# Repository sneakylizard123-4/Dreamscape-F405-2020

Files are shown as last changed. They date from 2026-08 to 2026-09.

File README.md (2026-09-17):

# Dreamscape F405

a 20x20mm flight controller for 3" fpv drone

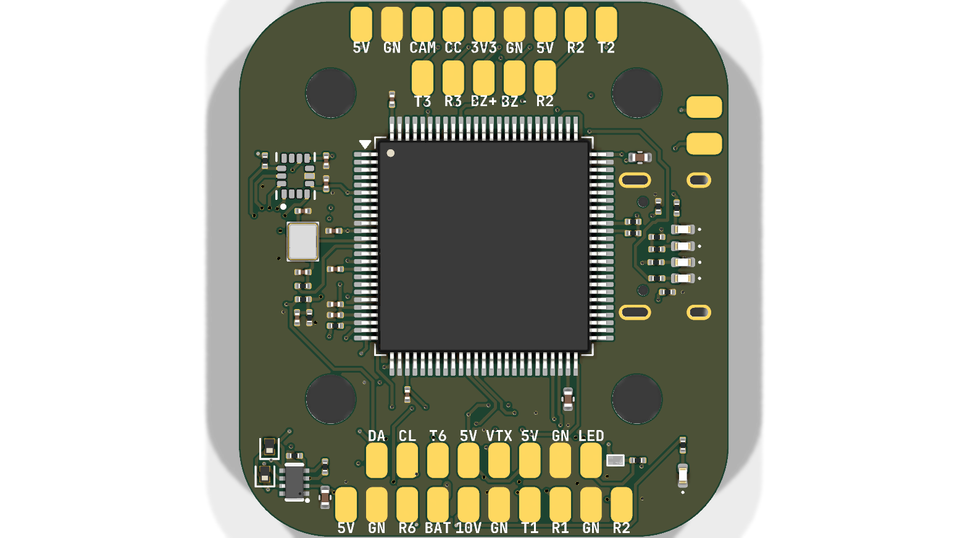
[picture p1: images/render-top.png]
PCB render


## Why I made this

would be a nice portfolio project
if it works i save lots of money too

## Pictures

| Page | Sheet |
|---|---|
| 1 | [Root / block diagram](images/schematic/Dreamscape-F405-2020.png) |
| 2 | [Power](images/schematic/Dreamscape-F405-2020-Power.png) |
| 3 | [Sensors](images/schematic/Dreamscape-F405-2020-Sensors.png) |
| 4 | [Blackbox](images/schematic/Dreamscape-F405-2020-Blackbox.png) |
| 5 | [OSD](images/schematic/Dreamscape-F405-2020-OSD.png) |
| 6 | [STM32](images/schematic/Dreamscape-F405-2020-STM32.png) |
| 7 | [Pads / connectors](images/schematic/Dreamscape-F405-2020-Pads.png) |
| 8 | [USB](images/schematic/Dreamscape-F405-2020-USB.png) |

## Features

- **MCU**: STM32F405VGT6
- **IMU**: ICM-42688-P
- **Barometer**: BMP280
- **OSD**: AT7456E (MAX7456-compatible)
- **Blackbox**: full-size microSD slot
- **Receiver**: dedicated JST-SH 4-pin ExpressLRS connector
- **UARTs**: 4 exposed plus I2C pads
- **Power**:
  - Battery input up to 6S
  - 5 V rail: onboard buck regulator
  - 3.3 V rail: TLV75733 LDO
  - 10 V rail: separate buck to feed camera/VTX
  - Onboard battery voltage ADC divider and ESC current sensor input
- **Extras**: beeper driver, neopixel LED strip driver, status LEDs

## Power tree

```mermaid
graph LR
    BAT[Battery +BATT] --> BUCK10[LMR51430 buck]
    BAT --> BUCK5[LMR51430 buck]
    BUCK10 -->|10 V, switched by 10V_EN| R10[CAM / VTX]
    BUCK5 -->|+5V_BUCK| MUX[TPS2116 power mux]
    USB[USB +5V] --> MUX
    MUX -->|system +5V| PERIPH[OSD / ELRS / peripherals]
    PERIPH --> LDO[TLV75733 LDO]
    LDO -->|+3.3V| MCU[STM32F405 / sensors]
```

## Pinout

Solder pads along the edge:

| Pad | Function | Pad | Function |
|---|---|---|---|
| `BAT` | Battery positive | `G` | Ground |
| `3v3` | 3.3 V out | `5v` | 5 V out |
| `10v` | 10 V out (switchable) | `CUR` | ESC current sense in |
| `TEL` | ESC telemetry | `CC` | Camera control |
| `CAM` | Video in from camera | `VTX` | Video out to VTX |
| `M1`-`M4` | Motor PWM outputs | `LED` | Addressable LED strip |
| `BZ+`/`BZ-` | Beeper | `SDA`/`SCL` | I2C |
| `T1`/`R1` | UART1 TX/RX | `T2`/`R2` | UART2 TX/RX |
| `T3`/`R3` | UART3 TX/RX | `T6`/`R6` | UART6 TX/RX |

Connectors:

| Connector | Pins | Use |
|---|---|---|
| J41 - JST-SH 8-pin vertical | BAT, GND, CUR, TEL, M1-M4 | battery + ESC harness |
| J42 - JST-SH 4-pin horizontal | 5V, GND, TX, RX | ExpressLRS receiver |

## Assembly

you probably should get pcba

solder front side first.
hand solder back side

## Flashing

drag the `.bin` onto the mounted DFU drive using the Betaflight Configurator firmware flasher.

Notes:
- If DFU is not accessible, flash via SWD with an ST-Link and `STM32_Programmer_CLI` or OpenOCD instead.

## Known Issues

- Board hasn't been manufactured yet.

## Credits

- OpenDrone
- Betaflight project - firmware this board will run
- STMicroelectronics / TDK / Bosch / Analog Devices datasheets for part reference designs

---

## BOM

| Refs | Part | Package / Footprint | Notes |
|---|---|---|---|
| U1 | STM32F405VGT6 | LQFP-100 14x14 mm | main MCU, 168 MHz Cortex-M4 |
| U6 | ICM-42688-P | LGA-14 | gyro + accel |
| U7 | BMP280 | LGA-8 | barometer |
| U8 | AT7456E | TQFP | MAX7456-compatible OSD |
| Y1 | 27 MHz crystal | 2016 4-pad | OSD clock |
| Card1 | TF-021B-H265 | microSD push-pull slot | blackbox logging |
| U3, U4 | LMR51430 | SOT-23-6 | 3 A buck regulators (10 V and 5 V) |
| U5 | TPS2116DRLR | SOT-583-8 | USB/buck power mux |
| U2 | TLV75733PDBV | SOT-23-5 | 3.3 V LDO |
| Q5, Q6 | AP1606 | DFN-3 | beeper and LED strip drivers |
| D3, D6 | RB161QS-40 | SOD-882 | Schottky diodes (power path) |
| L2, L3 | XRTC303020D4R7 | 3x3 mm | 4.7 uH power inductors |
| D2 | Blue LED | 0402 | status |
| D4, D5, D7 | Green LED | 0402 | power indicators |
| J41 | JST-SH 8-pin | SM08B-SHLS-TF | battery/ESC harness |
| J42 | JST-SH 4-pin | SM04B-SRSS-TB | ELRS receiver |
| R31, R29, R27, R23, R50 | 100 kOhm x5 | 0201 | |
| R2, R39, R49, R50 | 10 kOhm x4 | 0201 | VBAT divider / pull-ups |
| R28 | 39 kOhm | 0201 | buck feedback divider |
| R34, R33 | 7.5 kOhm x2 | 0201 | buck feedback dividers |
| R32 | 13.7 kOhm | 0201 | buck feedback |
| R30 | 6.49 kOhm | 0201 | buck feedback |
| R53, R52 | 75 Ohm x2 | 0201 | |
| R36 | 510 Ohm | 0201 | |
| R51 | 2.4 kOhm | 0201 | |
| R9 | 1 kOhm | 0201 | current sensor filter |
| C24, C25 | 4.7 uF 50 V x2 | 0805 | battery input |
| C29, C28, C34 | 22 uF x3 | 0603/0402 | buck outputs |
| C30 | 4.7 uF | 0402 | |
| C1, C22 | 2.2 uF x2 | 0402 | |
| C4, C36-C39, C43, C32, C26, C27 | 100 nF x10 | 0201 | decoupling |

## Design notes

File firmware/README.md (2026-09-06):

# Firmware

This board runs [Betaflight](https://betaflight.github.io/) (GPL-3.0), pinned here as a git submodule in `betaflight/`.

## Current version

- Submodule commit: `142ed9a` (master, 2026-08-28)

## Building

See `betaflight/` for the standard Betaflight build setup (arm-none-eabi-gcc + Makefile). The custom part for this board is a unified target config mapping:

- SPI1 = ICM-42688-P gyro/accel + BMP280 barometer
- SPI2 = AT7456E OSD
- SPI3 = microSD blackbox
- UART1/2/3/6 = pads T1-T6 / R1-R6
- motor timers, beeper, LED strip, VBAT/current ADC

## Updating the submodule

```sh
git submodule update --remote firmware/betaflight   # pull latest
```

Clone with submodules:

```sh
git clone --recursive <this repo>
```

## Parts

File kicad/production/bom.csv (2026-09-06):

Designator | Footprint | Quantity | Value | LCSC Part #
C1, C2 | 0805 | 2 | 4.7uF 50v | C98192
C10 | 0402 | 1 | 4.7uF | C23733
C11, C4 | 0402 | 2 | 22uF | C415703
C12, C13, C14, C15, C16, C17, C19, C21, C23, C25, C26, C27, C3, C5, C6, C9 | 0201 | 16 | 100n | C76939
C18, C20 | 0402 | 2 | 2.2uF
C22, C24 | 0201 | 2 | 20pF | C76923
C7, C8 | 0603 | 2 | 22uF | C2762594
CARD1 | TF-SMD_TF-021B-H265 | 1 | TF-021B-H265 | C498185
D1, D2, D3, D6 | 0402 | 4 | LED_1_Green | C965793
D4, D5 | D_SOD-882 | 2 | RB161QS-40_C28646385 | C28646385
D7 | 0402 | 1 | LED_1_Blue | C22355736
J35 | JST_SHL_SM08B-SHLS-TF_1x08-1MP_P1.00mm_Horizontal | 1 | Conn_01x08_MountingPin
J36 | JST_SH_SM04B-SRSS-TB_1x04-1MP_P1.00mm_Horizontal | 1 | Conn_01x04_MountingPin
J37 | USB_C_Receptacle_HRO_TYPE-C-31-M-12 | 1 | USB_C_Receptacle_USB2.0_16P
L1, L2 | IND-SMD_L3.0-W3.0_AFE303020S | 2 | XRTC303020D4R7MBCA | C39846837
Q1, Q2 | DFN-3L_L1.0-W0.6-P0.65-BR | 2 | AP1606 | C2849580
R1, R10, R24 | 0201 | 3 | 510R | C57784
R11, R12, R13, R16, R17, R19 | 0201 | 6 | 10k | C106225
R14, R15, R27, R28 | 0201 | 4 | 5.1k | C270344
R18, R2, R26, R4, R6 | 0201 | 5 | 100k | C270364
R20, R21 | 0201 | 2 | 1k | C270365
R22, R23 | 0201 | 2 | 75R | C274878
R25 | 0201 | 1 | 2.4k | C166281
R3 | 0201 | 1 | 6.49k | C2107920
R5 | 0201 | 1 | 13.7k | C320695
R7 | 0201 | 1 | 39k | C473053
R8, R9 | 0201 | 2 | 7.5k | C474437
U1, U5 | SOT-23-5 | 2 | TLV75733PDBV
U11, U12 | SW-SMD_4P-L3.0-W2.0-P0.85-LS3.5 | 2 | TS2306A 240GF MSM 9_C2976675 | C2976675
U2, U3 | SOT-23-6 | 2 | LMR51430
U4 | SOT-583-8_L2.1-W1.6-P0.50-LS1.6-BL | 1 | TPS2116DRLR | C3235557
U6 | PQFN50P300X250X97-14N | 1 | ICM-42688-P
U7 | Bosch_LGA-8_2x2.5mm_P0.65mm_ClockwisePinNumbering | 1 | BMP280
U8 | 21-0108G_U28E-5_MXM | 1 | AT7456E
U9 | LQFP-100_14x14mm_P0.5mm | 1 | STM32F405VGTx
X1 | CRYSTAL-SMD_4P-L2.5-W2.0-BL-A | 1 | X32258MOB4SI | C2682775
Y1 | Crystal_SMD_2016-4Pin_2.0x1.6mm | 1 | 27MHz

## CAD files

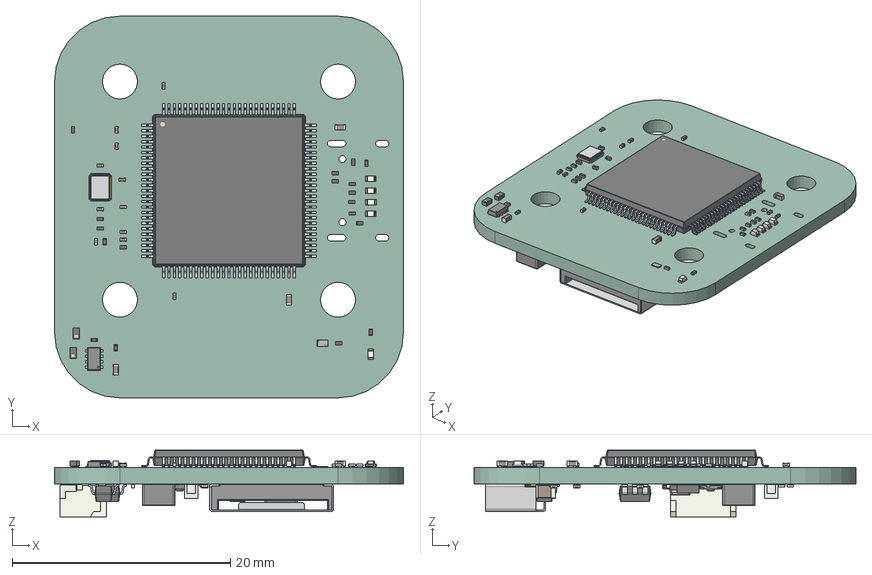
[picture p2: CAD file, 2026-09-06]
cad/Dreamscape-F405-2020.step
32.0 x 35.0 x 6.14 mm
LED_0402_1005Metric x 5
R_0201_0603Metric x 28
C_0201_0603Metric x 18
C_0402_1005Metric x 5
SOT-583-8_L2.1-W1.6-P0.50-LS1.6-BL
LQFP-100_14x14mm_P0.5mm
CRYSTAL-SMD_4P-L2.5-W2.0-BL-A
DFN-3L_L1.0-W0.6-H0.5-P0.65-BR x 2
D_SOD-882 x 2
IND-SMD_L3.0-W3.0_AFE303020S x 2
SW-SMD_4P-L3.0-W2.0-P0.85-LS3.5 x 2
TF-SMD_TF-021B-H265
C_0603_1608Metric x 2
SOT-23-6 x 2
Crystal_SMD_2016-4Pin_2.0x1.6mm
C_0805_2012Metric x 2
JST_SH_SM04B-SRSS-TB_1x04-1MP_P1.00mm_Horizontal
SOT-23-5 x 2
Bosch_LGA_8_2x25mm_P065mm_ClockwisePinNumbering
Dreamscape-F405-2020_PCB

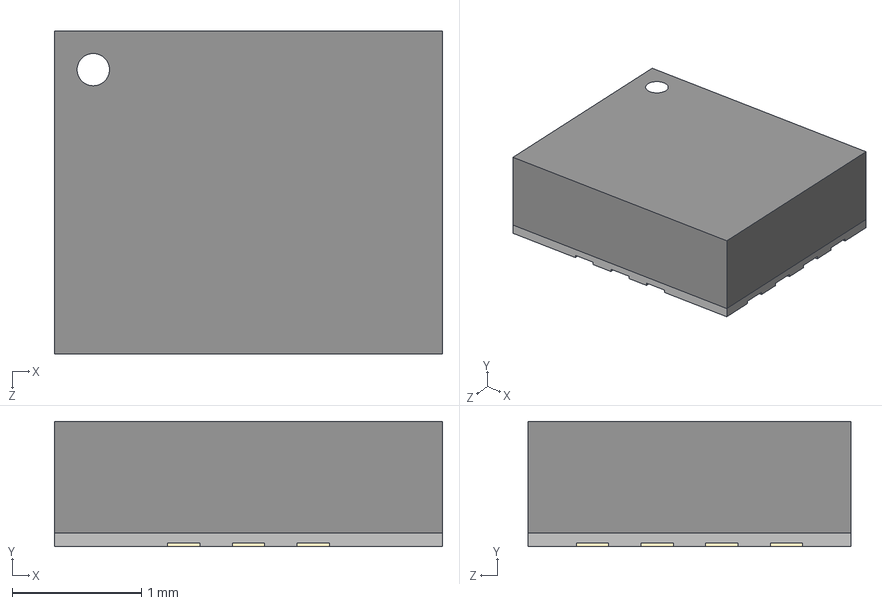
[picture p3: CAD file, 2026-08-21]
kicad/parts/ICM_42688_P/ICM-42688-P.step
3.00 x 0.97 x 2.50 mm

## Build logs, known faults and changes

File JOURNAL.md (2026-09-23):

---
title: Dreamscape F405 devlog
author: sneakylizard123-4
description: Building a custom STM32F405 flight controller from scratch
created_at: 2026-08-02
---

# August 2: Picking a brain (and the parts around it)

## What I did:

- started the project
- picked the brain: STM32F405, the same chip most modern flight controllers run
- settled on a 20x20 mounting pattern so it fits standard quad stacks
- planning a 3" fpv drone around it
- picked the rest of the part list:
    - ICM-42688-P IMU
    - BMP280 barometer
    - AT7456E OSD

## Why:

- last builds used off-the-shelf flight controllers, this one is mine end to end
- everything on one board, no stacking random modules

## Screenshots:

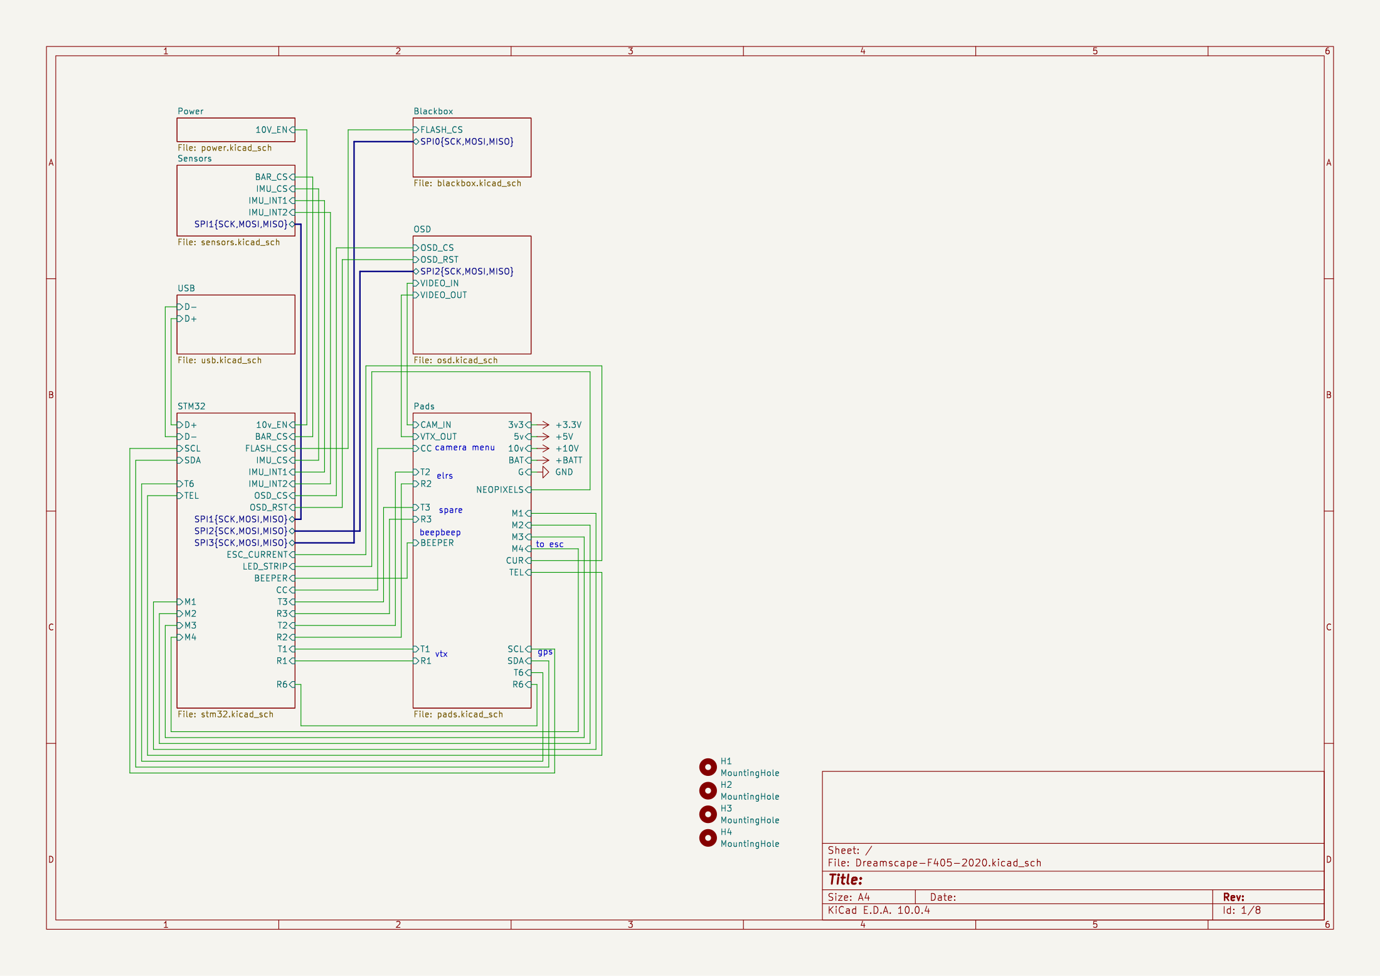
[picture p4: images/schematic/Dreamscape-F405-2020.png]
the plan


**Total time spent: 3 hours**

# August 5: Power sheet

## What I did:

- first sheet: power
- two LMR51430 bucks: a 5v rail always on, a 10v rail gated by an enable pin
- TLV75733 LDO drops 5v to 3.3v for the logic
- TPS2116 power mux picks between the 5v buck and USB 5v
- resistor divider onto an ADC pin to read battery voltage

## Why:

- camera and VTX want 10v but only when armed, so the gate keeps them off on the bench
- the mux means the board boots off USB with no battery plugged in
- battery divider sized so 6S stays under the MCU's 3.3v

## Screenshots:

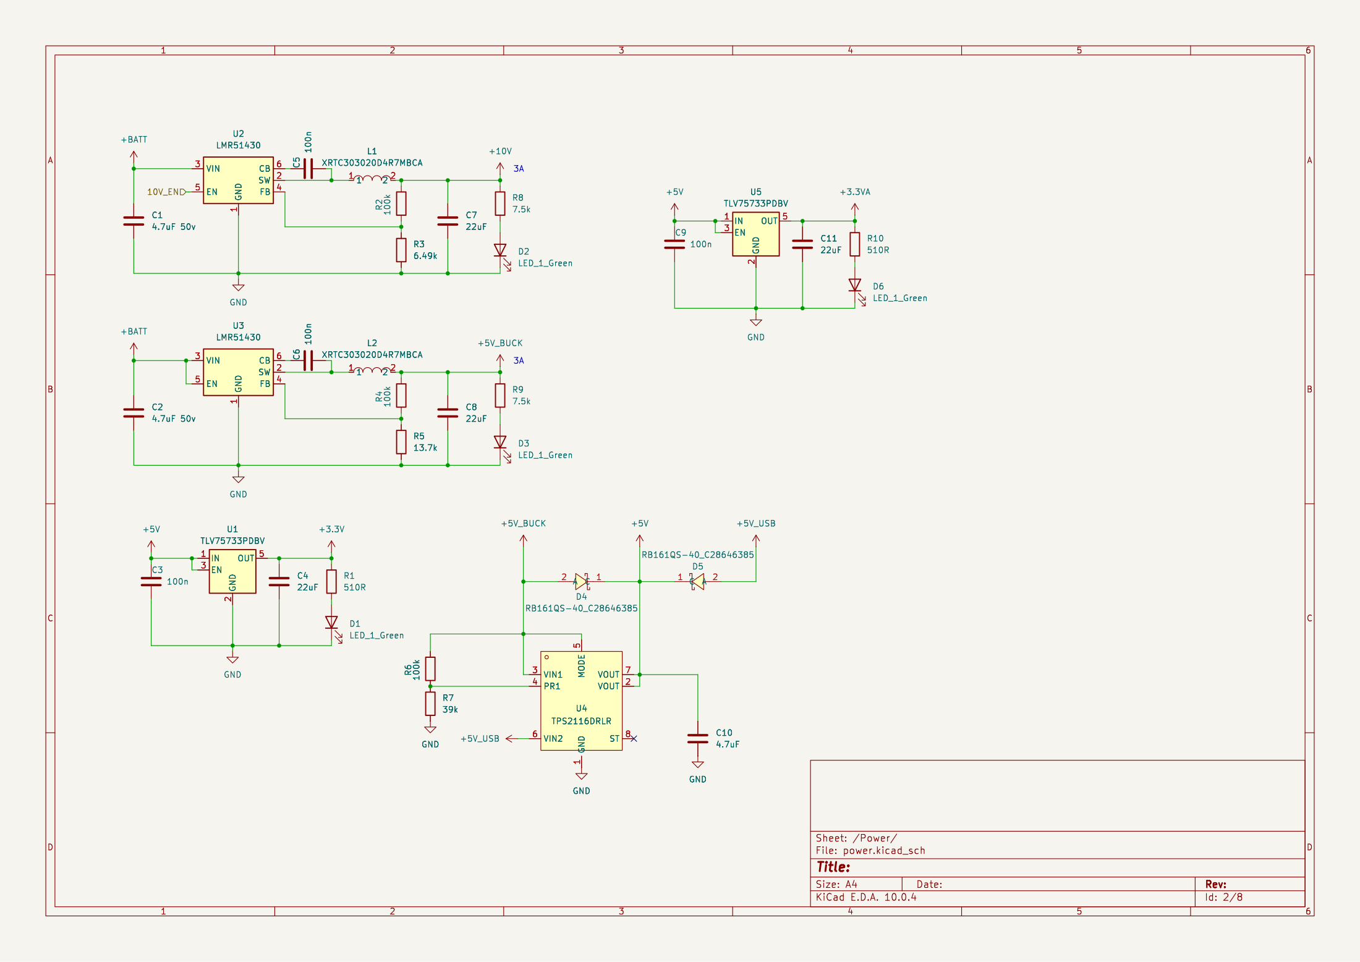
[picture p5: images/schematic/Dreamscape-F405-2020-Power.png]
power sheet


**Total time spent: 3 hours**

# August 8: Sensors sheet

## What I did:

- ICM-42688-P IMU
- BMP280 barometer
- both on the same SPI1 bus, separate chip selects
- copied reference circuits for the decoupling

## Why:

- the IMU is the core of the flight controller, went with the modern part instead of the old 6xx series
- baro gives pressure hold for free, costs one more chip
- sharing one SPI bus saves pins, chip select keeps them from talking over each other

## Screenshots:

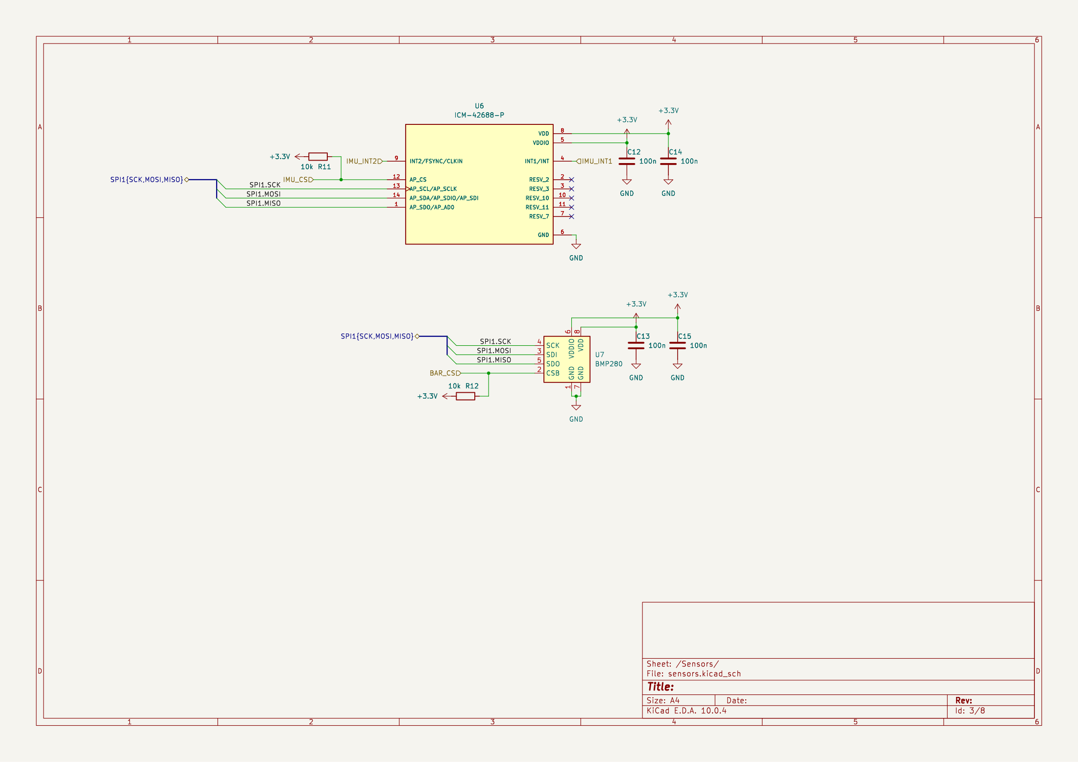
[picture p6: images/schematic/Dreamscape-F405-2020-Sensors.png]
sensors sheet


**Total time spent: 2 hours**

# August 11: Blackbox sheet

## What I did:

- microSD slot on its own SPI3 bus
- push-pull slot so a card clicks in
- card select pulled up, unused data lines left in SPI mode

## Why:

- blackbox logging writes constantly, didn't want it fighting the gyro for the bus
- a stuck card read could delay the IMU and wreck flight behavior

## Screenshots:

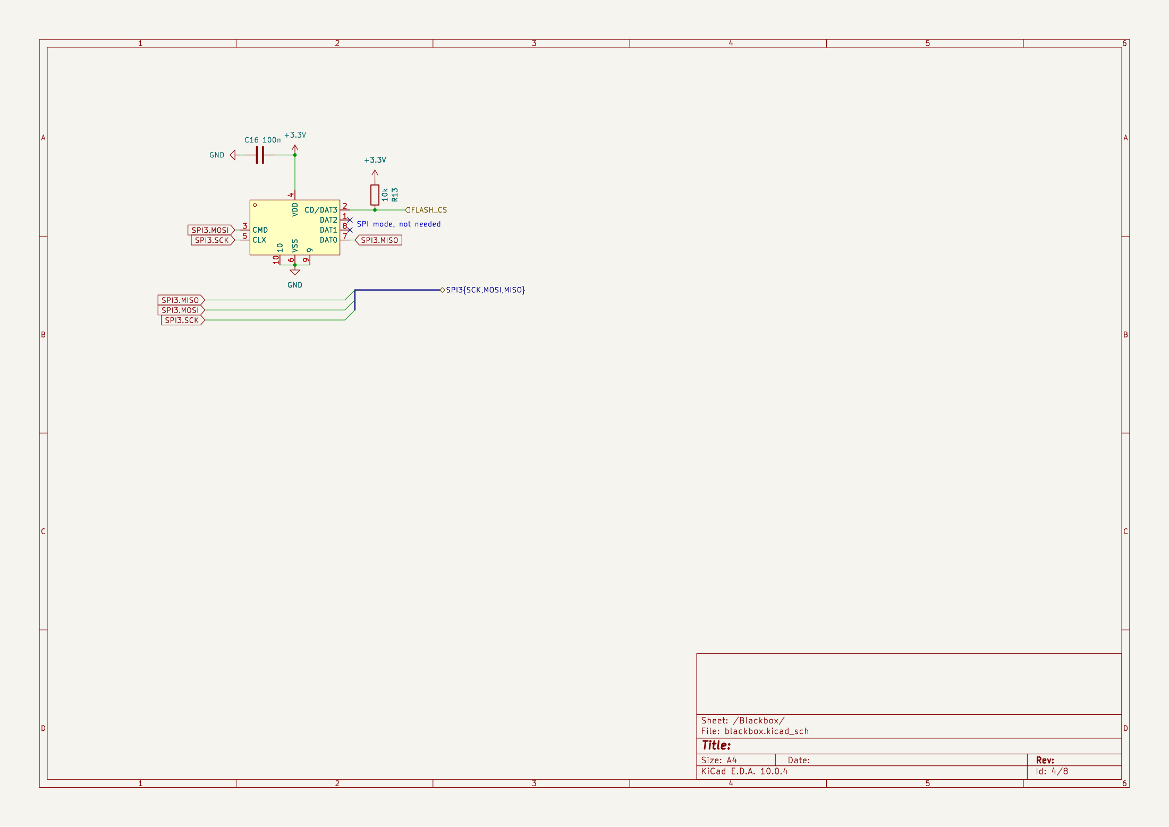
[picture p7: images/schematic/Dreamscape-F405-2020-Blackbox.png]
blackbox sheet


**Total time spent: 2 hours**

# August 14: OSD sheet

## What I did:

- AT7456E for the overlay
- 27MHz crystal it needs
- kept the signal path straight: Camera -> OSD -> VTX

## Why:

- AT7456E is everywhere in FPV, tons of reference material
- the video path is analog and easy to mess up, short and clean is the only sane option

## Screenshots:

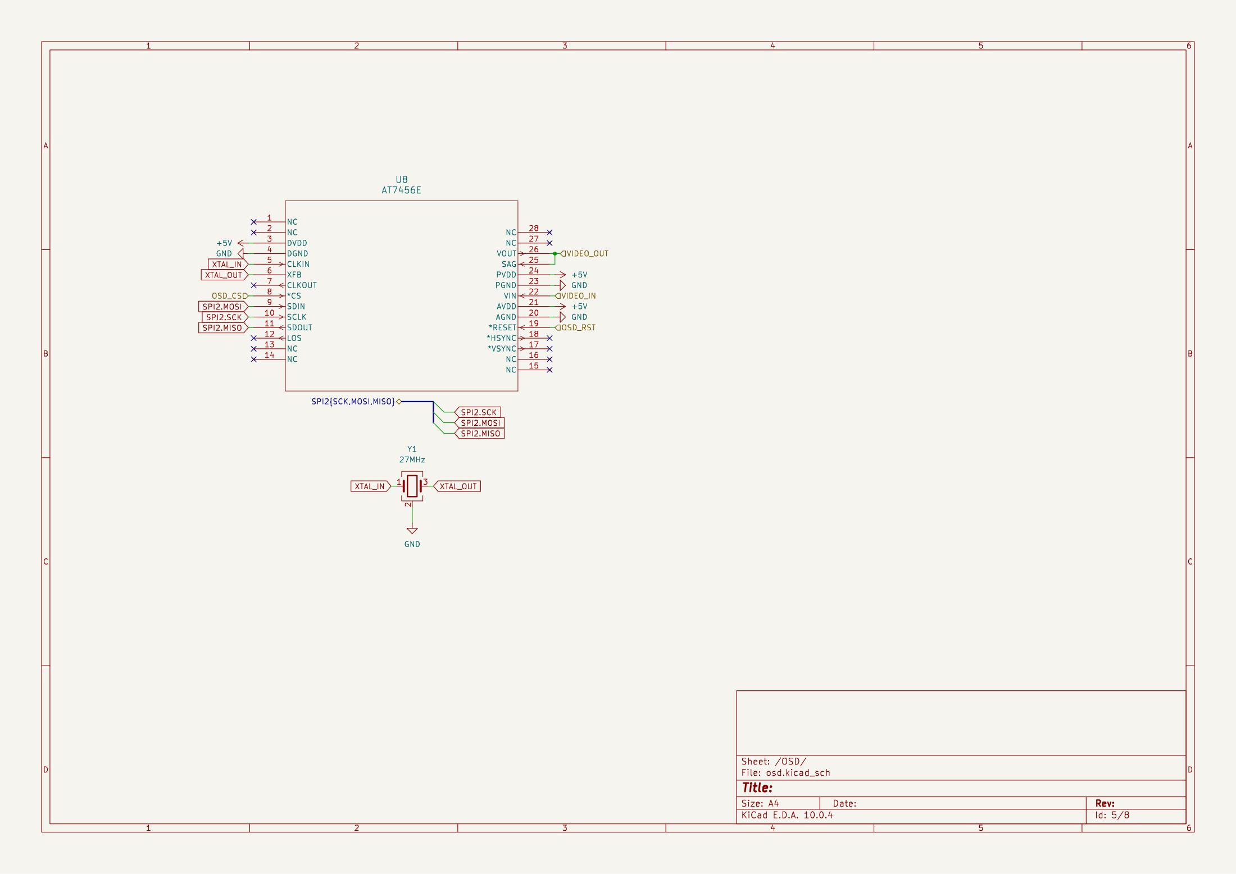
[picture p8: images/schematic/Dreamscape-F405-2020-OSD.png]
osd sheet


**Total time spent: 2 hours**

# August 18: STM32 sheet

## What I did:

- started the f405 sheet
- 8MHz crystal on PH0/PH1
- this chip has USB built in, no transceiver chip needed
- spent a long time on pin assignment, matching each pad to pins with the right alternate function

## Why:

- pin choice decides the whole board, worth doing carefully upfront instead of rerouting later
- USB means flashing over the type-C port, no extra chip

## Screenshots:

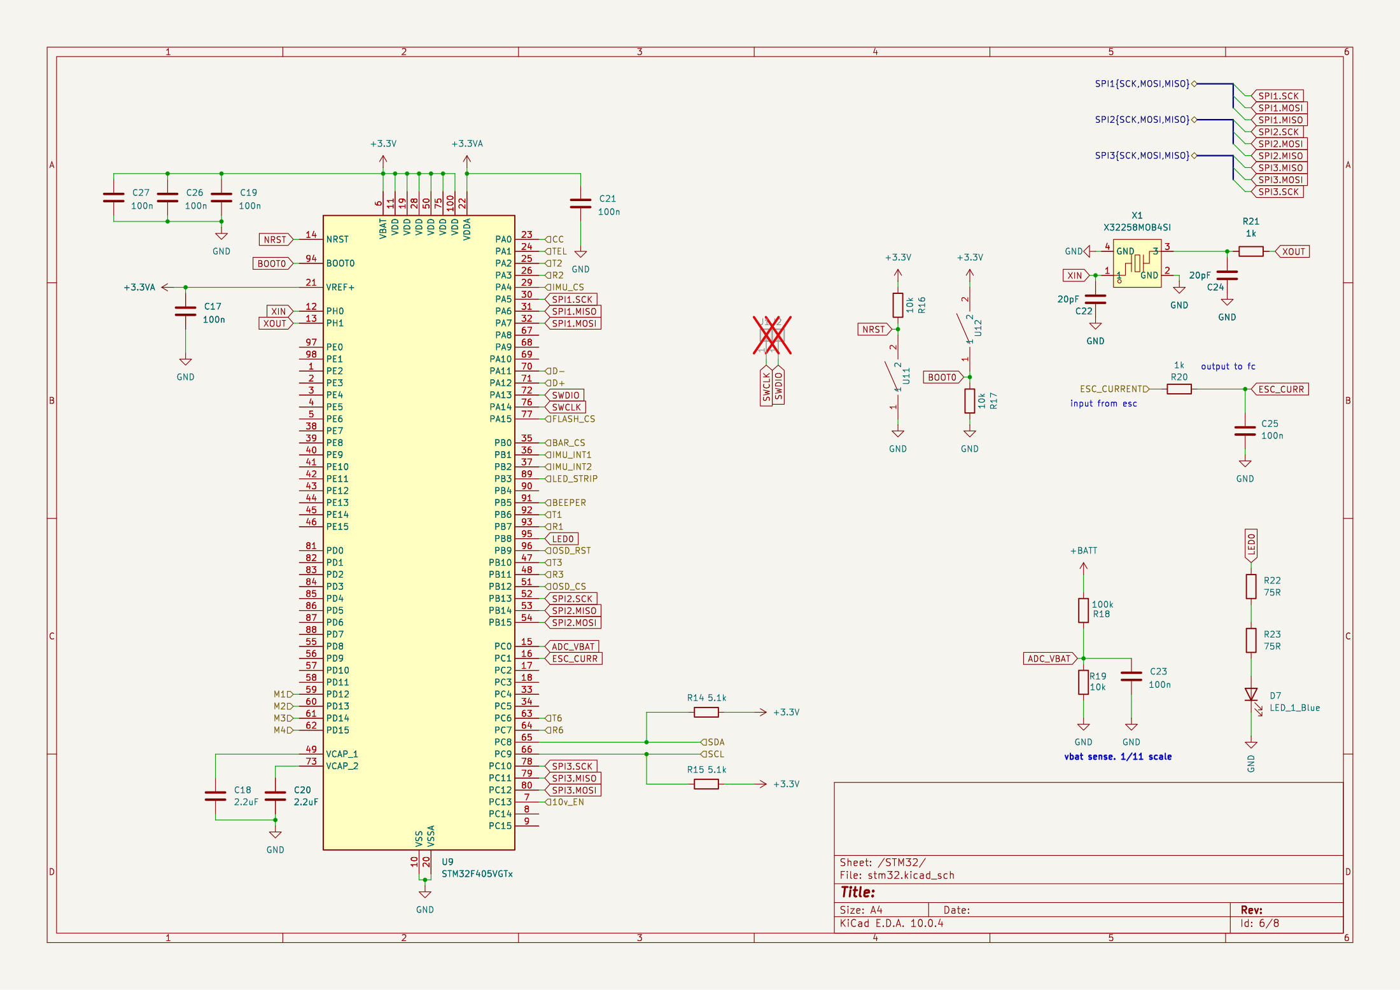
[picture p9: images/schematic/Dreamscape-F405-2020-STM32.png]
stm32 sheet


**Total time spent: 4 hours**

# August 20: Pads sheet

## What I did:

- pads sheet
- JST-SH connector for the ESCs and the battery/telemetry/current harness
- separate header for the ELRS receiver
- modeled on the F405 Mini pad layout

## Why:

- JST-SH is what flight controllers actually ship with, plugs match common motor and ext boards
- separate ELRS connector keeps the radio wiring clean

## Screenshots:

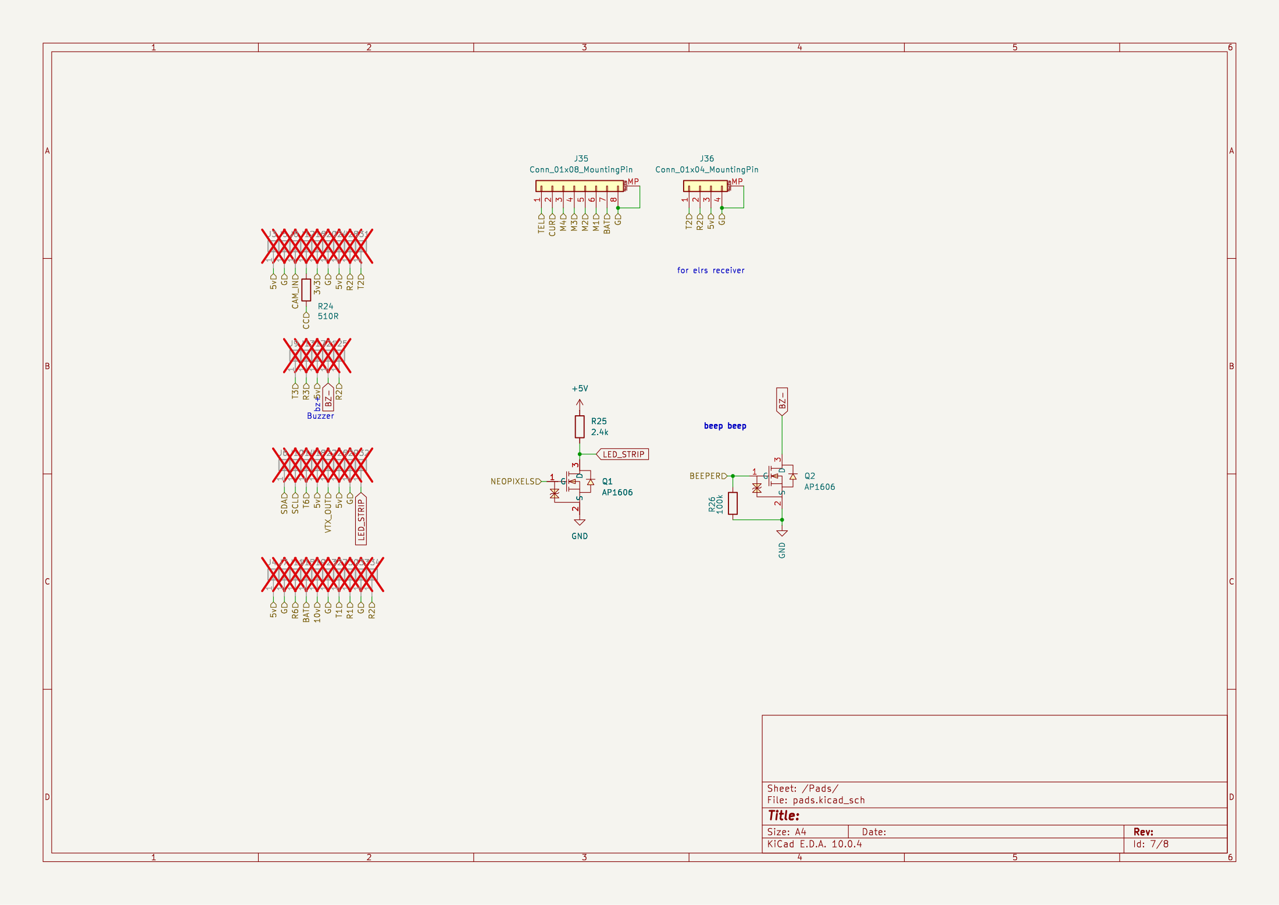
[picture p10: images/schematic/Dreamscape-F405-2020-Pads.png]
pads sheet


**Total time spent: 3 hours**

# August 22: USB-C sheet

## What I did:

- USB-C sheet
- VBUS goes into the power mux
- 5.1k CC pull-downs

## Why:

- standard USB-C connector is cheap and everywhere
- plugging in USB powers the board through the mux, no battery needed to flash

## Screenshots:

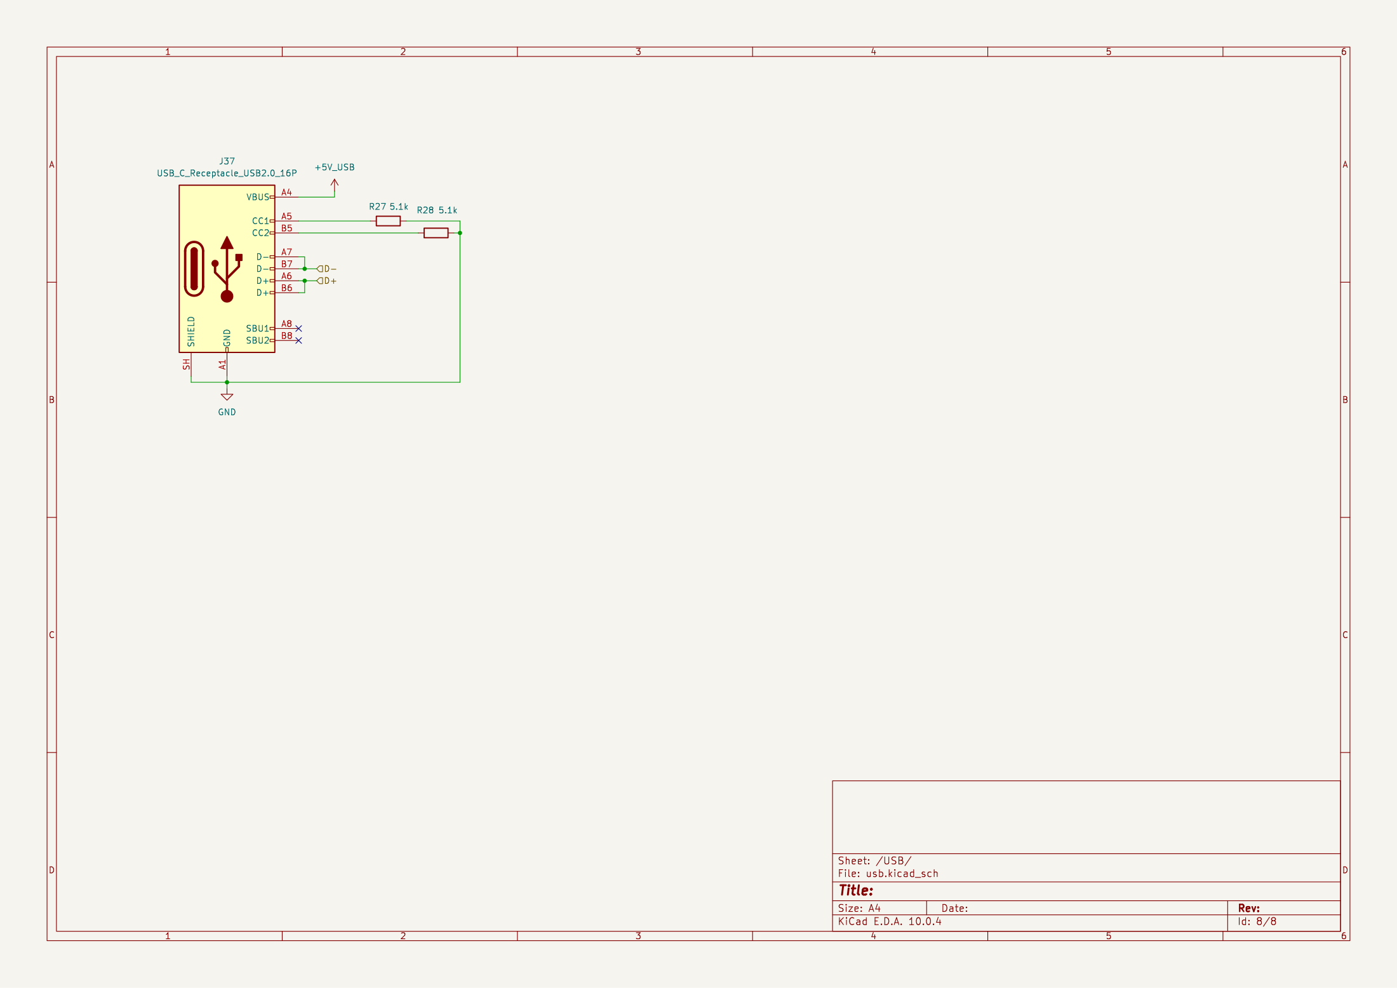
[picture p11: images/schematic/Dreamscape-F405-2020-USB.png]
usb sheet


**Total time spent: 1.5 hours**

# August 25: Placement and start of routing

## What I did:

- started the PCB
- F405 in the center
- power stage along one edge
- analog stuff kept away from the buck converters
- inner ground plane

## Why:

- traces near the power stage carry switching noise, keeping analog away saves headaches
- the ground plane gives clean return paths

## Screenshots:

board so far

**Total time spent: 4 hours**

# August 27: Routing done (+ DRC)

## What I did:

- finished routing both layers
- ran DRC: clearance issues near the crystal, some silk too close to pads
- retraced the current sense line, it ran past both bucks on its way to the ESC

## Why:

- power traces carry huge ripple, the current sense pickoff needed a cleaner route
- left the cosmetic DRC leftovers for the cleanup pass

## Screenshots:

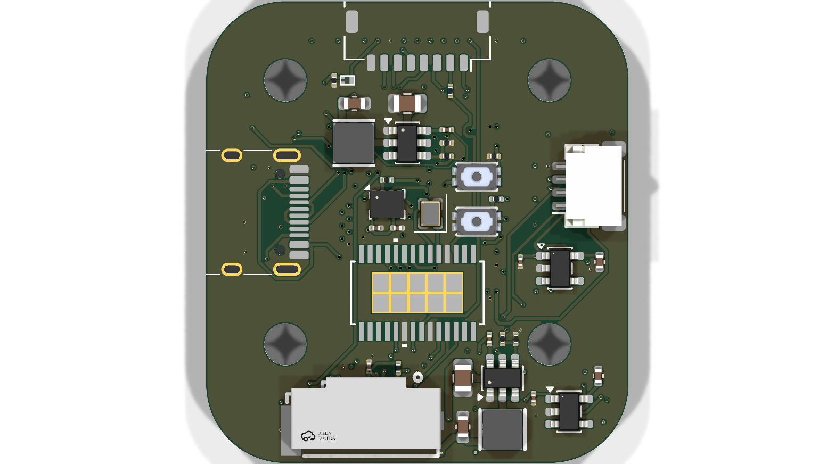
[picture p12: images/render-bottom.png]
finished routing


**Total time spent: 6 hours**

# August 28: Silkscreen labels on the pads

## What I did:

- labeled every pad in silkscreen
- 5v, gn, 3v3, 10v, bat, bz, led, cam, vtx, the UART pads
- shortened names so they fit on a 20x20 board

## Why:

- every real flight controller has this, makes wiring the stack at the bench not guesswork
- 0201 parts and pad labels in one place is cramped, spacing got fiddly, expect careful soldering

## Screenshots:

Fresh PCB render with the pad labels

**Total time spent: 1 hour**

# August 29: Design review by a second pair of eyes

## What I did:

- Forge wants the design sanity-checked by someone else, so I sent the board out for review
- the reviewer mapped every MCU pin against the STM32F405 datasheet
- went through SPI1/2/3, the UARTs, USB, the power tree, and the motor timers
- the reviewer found a real bug: the I2C pads landed on pins that can't do I2C on the F405

## Why:

- a reviewed design is cheaper to fix than a fabbed one
- I had assumed the pads were fine, fresh eyes caught what I'd stopped looking at

## Screenshots:

stm32 sheet under review

**Total time spent: 3 hours**

# August 30: Fixing the I2C wiring

## What I did:

- SDA pad was on PC8: no I2C alternate function there at all
- SCL was on PC9, which is actually the I2C3 SDA pin, so they were backwards too
- re-routed SDA to PC9 and SCL to PA8, the pins that really can do I2C3
- re-ran ERC and DRC after the change
- regenerated the schematic PNGs so the repo images match the fix

## Why:

- the chip is labeled I2C3 on those pins in the datasheet, the pad wiring had drifted from it
- catching it before fab saved a dead pair of pads in the final board

## Screenshots:

pads sheet after fix

**Total time spent: 2 hours**

# August 31: Firmware drop-in and STEP export

## What I did:

- added Betaflight as a git submodule under firmware/
- noted which target config to build from: SPI1 gyro and baro, SPI2 OSD, SPI3 SD, UART pads for the radio and GPS
- exported the board as STEP for the CAD requirement

## Why:

- the board is built to run stock Betaflight, keeping it as a submodule pins the upstream version we target
- the STEP export is required for submission and doubles as a sanity check of the 3D models

## Screenshots:

board render for the CAD pass

**Total time spent: 2 hours**

# September 1: Repo cleanup and submission prep

## What I did:

- rewrote the README to the Hack Club template
- reworked the journal into the what/why/screenshots format
- added a gitignore so the kicad autosave junk stays out of the repo
- noticed the JST-SH connector has no 3D model, so it shows up missing in the STEP export

## Why:

- submission needs the repo organized: BOM, sources, STEP, firmware, folders
- a clean repo is part of the review, messy history looks unfinished

## Screenshots:

top render for the README

**Total time spent: 2 hours**

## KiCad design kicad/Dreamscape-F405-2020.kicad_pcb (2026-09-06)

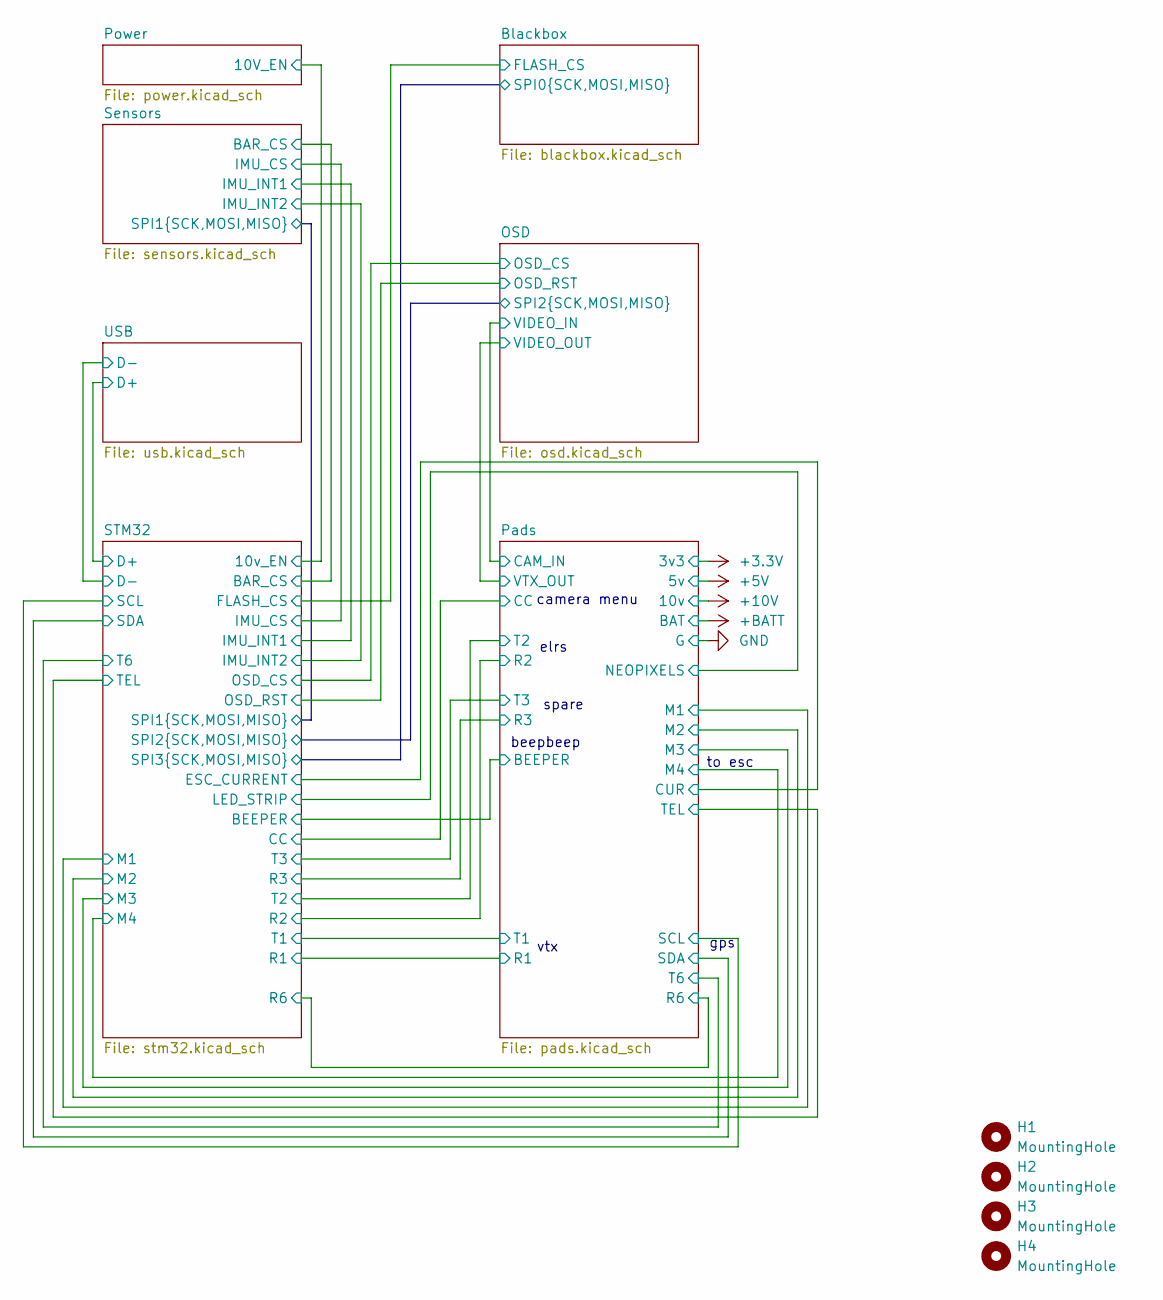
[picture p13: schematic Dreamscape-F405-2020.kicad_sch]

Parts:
H1, H2, H3, H4: MountingHole; MountingHole_3.2mm_M3

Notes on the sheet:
beepbeep
gps
spare
camera menu
elrs
to esc
vtx

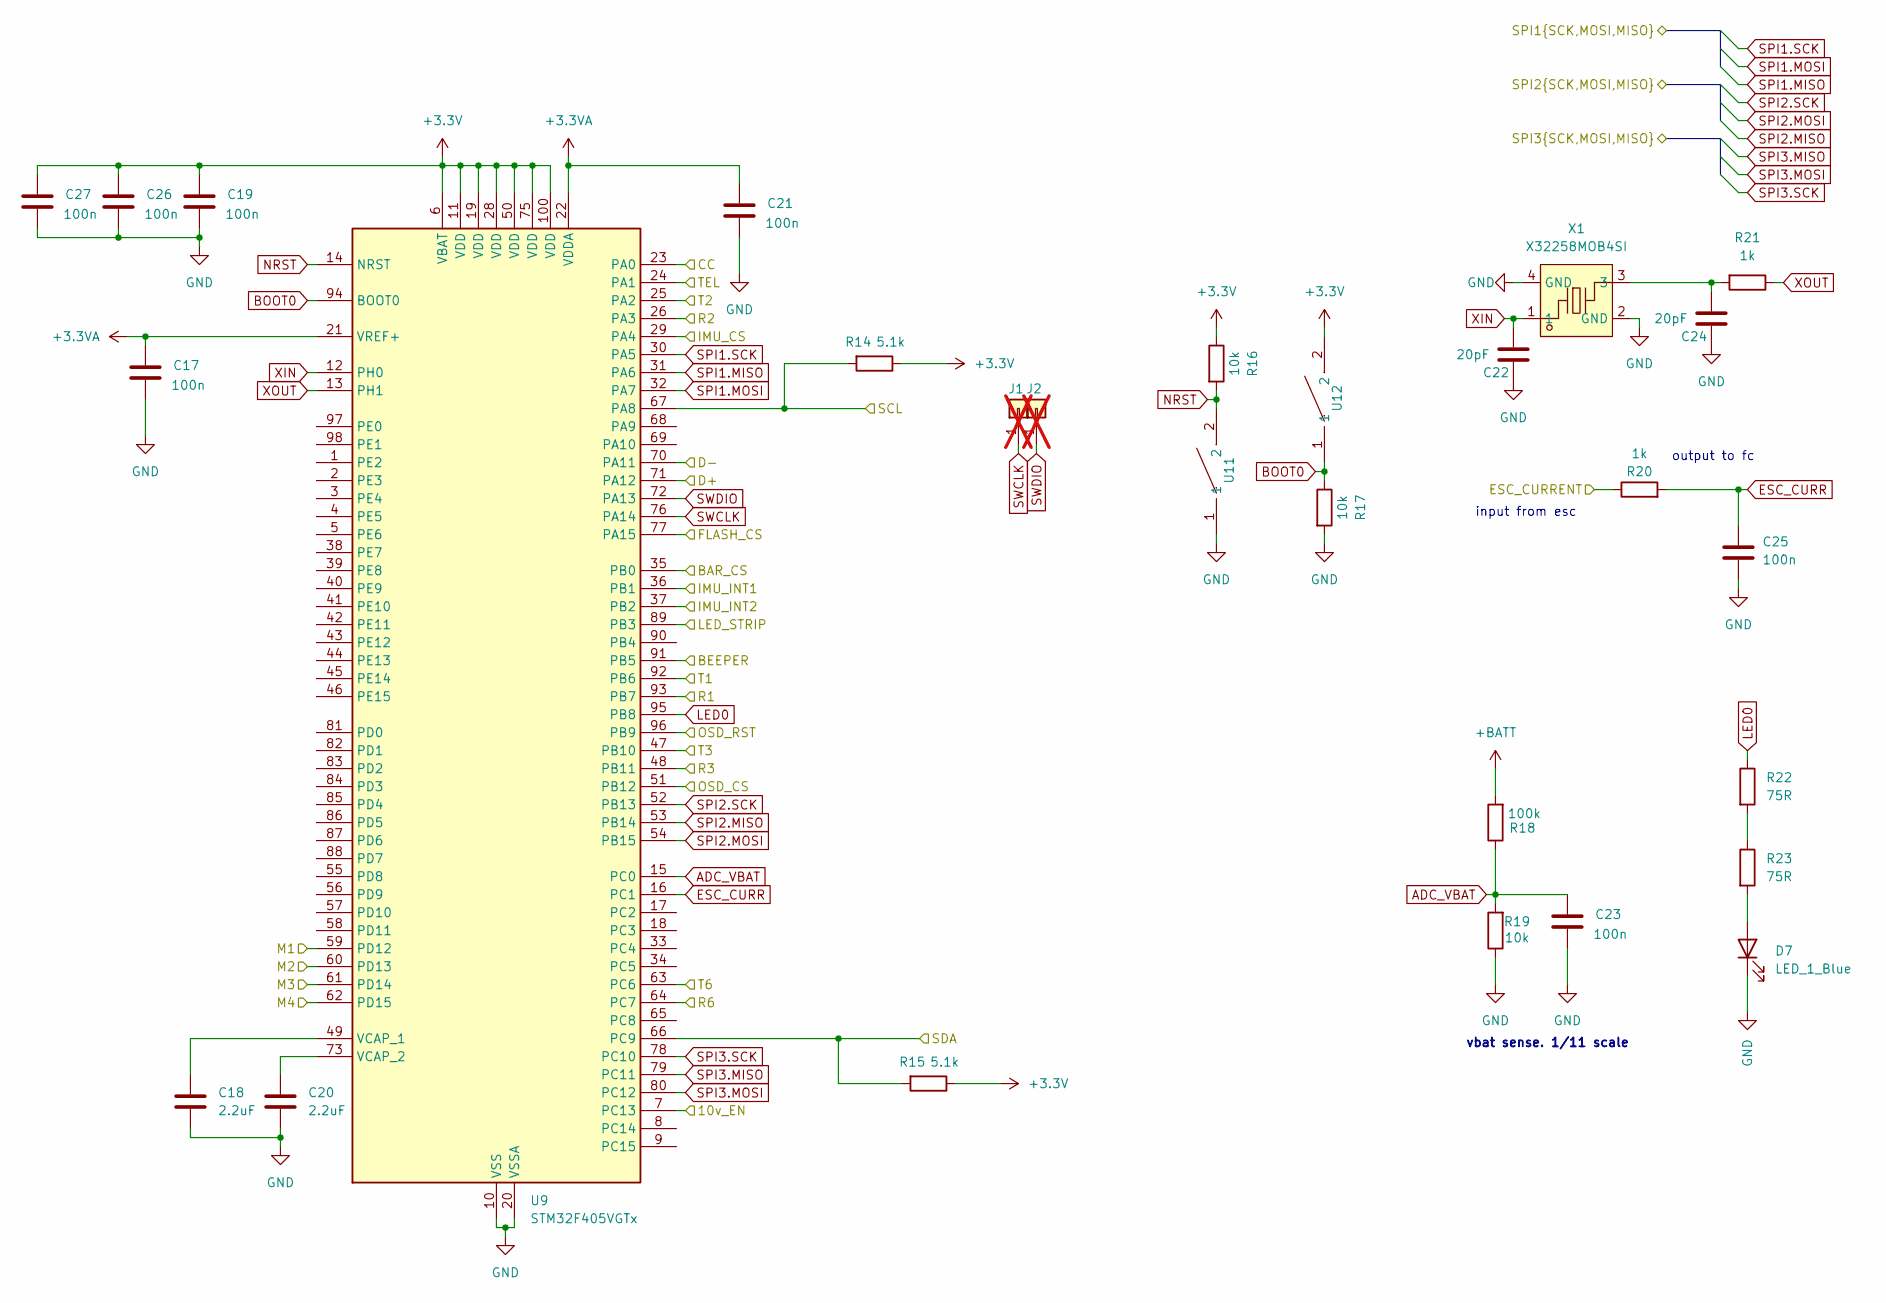
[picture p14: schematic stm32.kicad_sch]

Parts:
C17, C19, C21, C23, C25, C26, C27: 100n; C_0201_0603Metric; MPN GRM033R61E104KE14D; LCSC C76939
C18, C20: 2.2uF; C_0402_1005Metric
C22, C24: 20pF; C_0201_0603Metric; MPN GRM0335C1H200JA01D; LCSC C76923
D7: LED_1_Blue; LED_0402_1005Metric; MPN XL-1005UBC; LCSC C22355736
J1, J2: 5V; small_pad; not fitted
R14, R15: 5.1k; R_0201_0603Metric; MPN 0201WMF5101TEE; LCSC C270344
R16, R17, R19: 10k; R_0201_0603Metric; MPN RC0201FR-0710KL; LCSC C106225
R18: 100k; R_0201_0603Metric; MPN 0201WMF1003TEE; LCSC C270364
R20, R21: 1k; R_0201_0603Metric; MPN 0201WMF1001TEE; LCSC C270365
R22, R23: 75R; R_0201_0603Metric; MPN RC0201FR-0775RL; LCSC C274878
U9: STM32F405VGTx; LQFP-100_14x14mm_P0.5mm
U11, U12: TS2306A 240GF MSM 9_C2976675; SW-SMD_4P-L3.0-W2.0-P0.85-LS3.5; MPN TS2306A 240gf MSM 9; LCSC C2976675
X1: X32258MOB4SI; CRYSTAL-SMD_4P-L2.5-W2.0-BL-A; MPN X32258MOB4SI; LCSC C2682775

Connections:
+3.3V: C19.2, C26.2, C27.2, R14.1, R15.1, R16.1, U9.6 (VBAT), U9.11 (VDD), U9.19 (VDD), U9.28 (VDD), U9.50 (VDD), U9.75 (VDD), U9.100 (VDD), U12.2; also elsewhere on the board
+3.3VA: C17.2, C21.2, U9.21 (VREF+), U9.22 (VDDA); also elsewhere on the board
+BATT: R18.2; also elsewhere on the board
/Blackbox/FLASH_CS: U9.77 (PA15); also elsewhere on the board
/OSD/OSD_CS: U9.51 (PB12); also elsewhere on the board
/OSD/OSD_RST: U9.96 (PB9); also elsewhere on the board
/Pads/BEEPER: U9.91 (PB5); also elsewhere on the board
/Pads/CC: U9.23 (PA0); also elsewhere on the board
/Pads/CUR: R20.1; also elsewhere on the board
/Pads/M1: U9.59 (PD12); also elsewhere on the board
/Pads/M2: U9.60 (PD13); also elsewhere on the board
/Pads/M3: U9.61 (PD14); also elsewhere on the board
/Pads/M4: U9.62 (PD15); also elsewhere on the board
/Pads/NEOPIXELS: U9.89 (PB3); also elsewhere on the board
/Pads/R1: U9.93 (PB7); also elsewhere on the board
/Pads/R2: U9.26 (PA3); also elsewhere on the board
/Pads/R3: U9.48 (PB11); also elsewhere on the board
/Pads/R6: U9.64 (PC7); also elsewhere on the board
/Pads/SCL: R15.2, U9.66 (PC9); also elsewhere on the board
/Pads/SDA: R14.2, U9.67 (PA8); also elsewhere on the board
/Pads/T1: U9.92 (PB6); also elsewhere on the board
/Pads/T2: U9.25 (PA2); also elsewhere on the board
/Pads/T3: U9.47 (PB10); also elsewhere on the board
/Pads/T6: U9.63 (PC6); also elsewhere on the board
/Pads/TEL: U9.24 (PA1); also elsewhere on the board
/Power/10V_EN: U9.7 (PC13); also elsewhere on the board
/STM32/BAR_CS: U9.35 (PB0); also elsewhere on the board
/STM32/D+: U9.71 (PA12); also elsewhere on the board
/STM32/D-: U9.70 (PA11); also elsewhere on the board
/STM32/IMU_CS: U9.29 (PA4); also elsewhere on the board
/STM32/IMU_INT1: U9.36 (PB1); also elsewhere on the board
/STM32/IMU_INT2: U9.37 (PB2); also elsewhere on the board
ADC_VBAT: C23.2, R18.1, R19.2, U9.15 (PC0)
BOOT0: R17.1, U9.94 (BOOT0), U12.1
ESC_CURR: C25.1, R20.2, U9.16 (PC1)
GND: C17.1, C18.2, C19.1, C20.2, C21.1, C22.1, C23.1, C24.1, C25.2, C26.1, C27.1, D7.1 (K), R17.2, R19.1, U9.10 (VSS), U9.20 (VSSA), U9.27 (VSS), U9.74 (VSS), U9.99 (VSS), U11.1, X1.2 (GND), X1.4 (GND); also elsewhere on the board
LED0: R22.1, U9.95 (PB8)
NRST: R16.2, U9.14 (NRST), U11.2
unnamed: C24.2, R21.2, X1.3
unnamed: D7.2 (A), R23.2
unnamed: R22.2, R23.1
unnamed: C18.1, U9.49 (VCAP_1)
unnamed: C20.1, U9.73 (VCAP_2)
SPI1.MISO: U9.31 (PA6); also elsewhere on the board
SPI1.MOSI: U9.32 (PA7); also elsewhere on the board
SPI1.SCK: U9.30 (PA5); also elsewhere on the board
SPI2.MISO: U9.53 (PB14); also elsewhere on the board
SPI2.MOSI: U9.54 (PB15); also elsewhere on the board
SPI2.SCK: U9.52 (PB13); also elsewhere on the board
SPI3.MISO: U9.79 (PC11); also elsewhere on the board
SPI3.MOSI: U9.80 (PC12); also elsewhere on the board
SPI3.SCK: U9.78 (PC10); also elsewhere on the board
SWCLK: J1.1 (Pin_1_1), U9.76 (PA14)
SWDIO: J2.1 (Pin_1_1), U9.72 (PA13)
XIN: C22.2, U9.12 (PH0), X1.1
XOUT: R21.1, U9.13 (PH1)

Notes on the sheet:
input from esc
vbat sense. 1/11 scale
output to fc

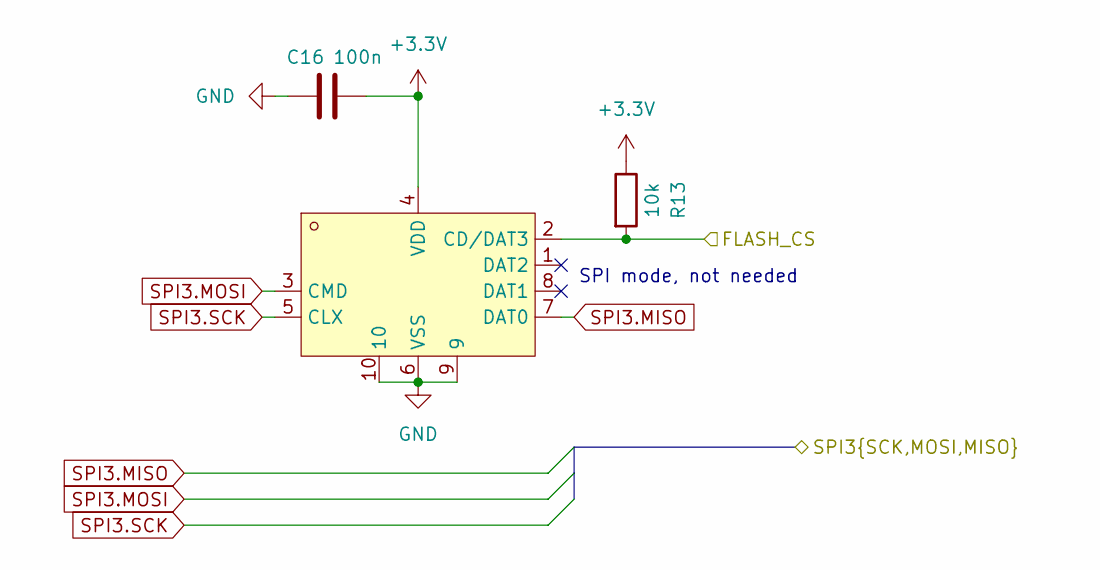
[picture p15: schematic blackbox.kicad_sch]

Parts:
C16: 100n; C_0201_0603Metric; MPN GRM033R61E104KE14D; LCSC C76939
Card1: TF-021B-H265; TF-SMD_TF-021B-H265; LCSC C498185
R13: 10k; R_0201_0603Metric; MPN RC0201FR-0710KL; LCSC C106225

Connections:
+3.3V: C16.1, Card1.4 (VDD), R13.1; also elsewhere on the board
/Blackbox/FLASH_CS: Card1.2 (CD/DAT3), R13.2; also elsewhere on the board
GND: C16.2, Card1.6 (VSS), Card1.9, Card1.10; also elsewhere on the board
SPI3.MISO: Card1.7 (DAT0); also elsewhere on the board
SPI3.MOSI: Card1.3 (CMD); also elsewhere on the board
SPI3.SCK: Card1.5 (CLX); also elsewhere on the board

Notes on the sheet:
SPI mode, not needed

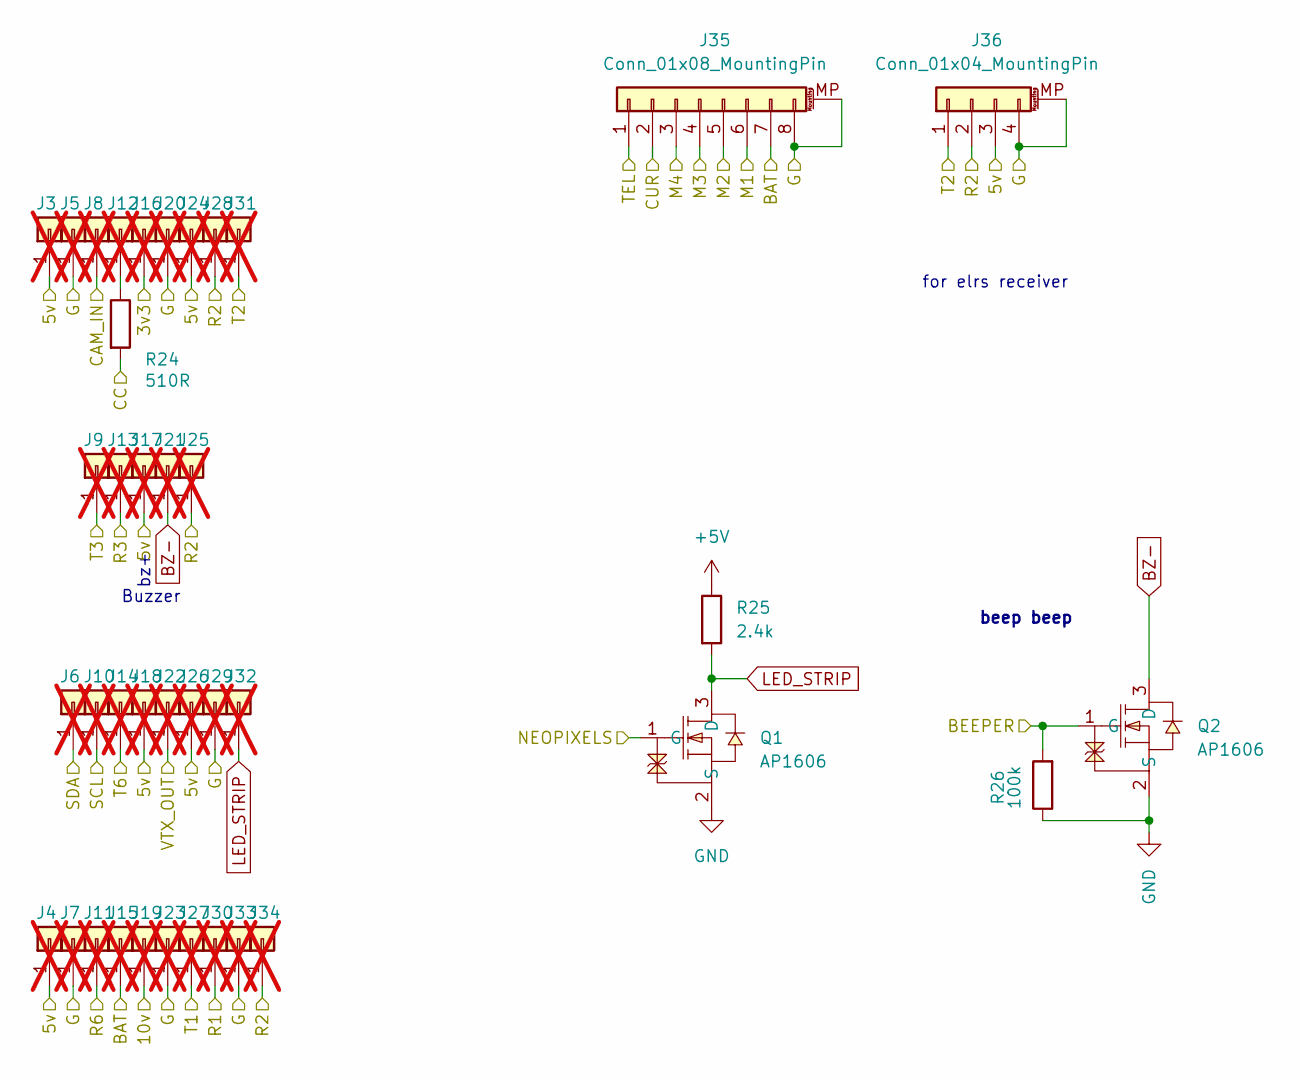
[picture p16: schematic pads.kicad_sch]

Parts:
J3, J4, J5, J6, J7, J8, J9, J10, J11, J12, J13, J14, J15, J16, J17, J18, J19, J20, J21, J22, J23, J24, J25, J26, J27, J28, J29, J30, J31, J32, J33, J34: 5V; small_pad; not fitted
J35: Conn_01x08_MountingPin; JST_SHL_SM08B-SHLS-TF_1x08-1MP_P1.00mm_Horizontal
J36: Conn_01x04_MountingPin; JST_SH_SM04B-SRSS-TB_1x04-1MP_P1.00mm_Horizontal
Q1, Q2: AP1606; DFN-3L_L1.0-W0.6-P0.65-BR; MPN AP1606; LCSC C2849580
R24: 510R; R_0201_0603Metric; LCSC C57784
R25: 2.4k; R_0201_0603Metric; LCSC C166281
R26: 100k; R_0201_0603Metric; MPN 0201WMF1003TEE; LCSC C270364

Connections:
+3.3V: J16.1 (Pin_1_1); also elsewhere on the board
+5V: J3.1 (Pin_1_1), J4.1 (Pin_1_1), J17.1 (Pin_1_1), J18.1 (Pin_1_1), J24.1 (Pin_1_1), J26.1 (Pin_1_1), J36.3, R25.1; also elsewhere on the board
+10V: J19.1 (Pin_1_1); also elsewhere on the board
+BATT: J15.1 (Pin_1_1), J35.7; also elsewhere on the board
/OSD/VIDEO_IN: J8.1 (Pin_1_1); also elsewhere on the board
/OSD/VIDEO_OUT: J22.1 (Pin_1_1); also elsewhere on the board
/Pads/BEEPER: Q2.1 (G), R26.2; also elsewhere on the board
/Pads/CC: R24.2; also elsewhere on the board
/Pads/CUR: J35.2; also elsewhere on the board
/Pads/M1: J35.6; also elsewhere on the board
/Pads/M2: J35.5; also elsewhere on the board
/Pads/M3: J35.4; also elsewhere on the board
/Pads/M4: J35.3; also elsewhere on the board
/Pads/NEOPIXELS: Q1.1 (G); also elsewhere on the board
/Pads/R1: J30.1 (Pin_1_1); also elsewhere on the board
/Pads/R2: J25.1 (Pin_1_1), J28.1 (Pin_1_1), J34.1 (Pin_1_1), J36.2; also elsewhere on the board
/Pads/R3: J13.1 (Pin_1_1); also elsewhere on the board
/Pads/R6: J11.1 (Pin_1_1); also elsewhere on the board
/Pads/SCL: J10.1 (Pin_1_1); also elsewhere on the board
/Pads/SDA: J6.1 (Pin_1_1); also elsewhere on the board
/Pads/T1: J27.1 (Pin_1_1); also elsewhere on the board
/Pads/T2: J31.1 (Pin_1_1), J36.1; also elsewhere on the board
/Pads/T3: J9.1 (Pin_1_1); also elsewhere on the board
/Pads/T6: J14.1 (Pin_1_1); also elsewhere on the board
/Pads/TEL: J35.1; also elsewhere on the board
BZ-: J21.1 (Pin_1_1), Q2.3 (D)
GND: J5.1 (Pin_1_1), J7.1 (Pin_1_1), J20.1 (Pin_1_1), J23.1 (Pin_1_1), J29.1 (Pin_1_1), J33.1 (Pin_1_1), J35.8, J35.MP (MountPin), J36.4, J36.MP (MountPin), Q1.2 (S), Q2.2 (S), R26.1; also elsewhere on the board
LED_STRIP: J32.1 (Pin_1_1), Q1.3 (D), R25.2
unnamed: J12.1 (Pin_1_1), R24.1

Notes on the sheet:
Buzzer
beep beep
bz+
for elrs receiver

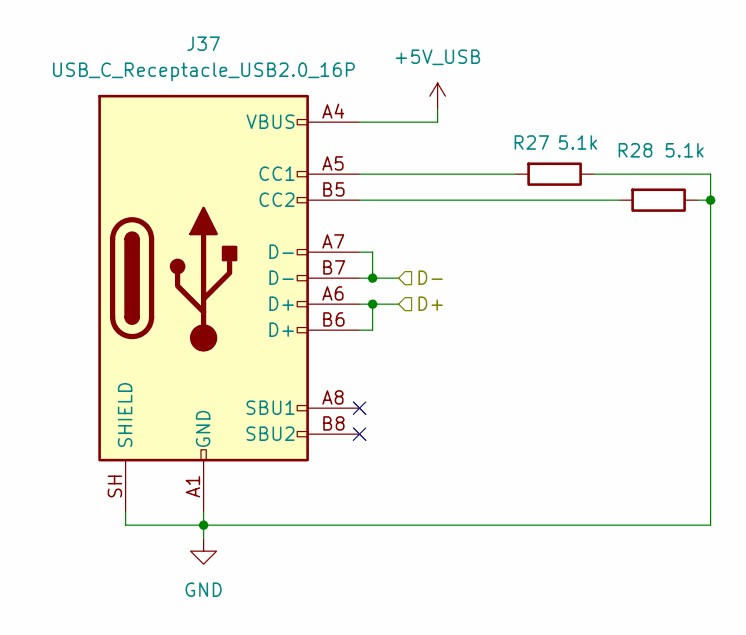
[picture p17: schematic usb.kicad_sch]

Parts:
J37: USB_C_Receptacle_USB2.0_16P; USB_C_Receptacle_HRO_TYPE-C-31-M-12
R27, R28: 5.1k; R_0201_0603Metric; MPN 0201WMF5101TEE; LCSC C270344

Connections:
+5V_USB: J37.A4 (VBUS), J37.A9 (VBUS), J37.B4 (VBUS), J37.B9 (VBUS); also elsewhere on the board
/STM32/D+: J37.A6 (D+), J37.B6 (D+); also elsewhere on the board
/STM32/D-: J37.A7 (D-), J37.B7 (D-); also elsewhere on the board
GND: J37.A1 (GND), J37.A12 (GND), J37.B1 (GND), J37.B12 (GND), J37.SH (SHIELD), R27.1, R28.1; also elsewhere on the board
unnamed: J37.A5 (CC1), R27.2
unnamed: J37.B5 (CC2), R28.2

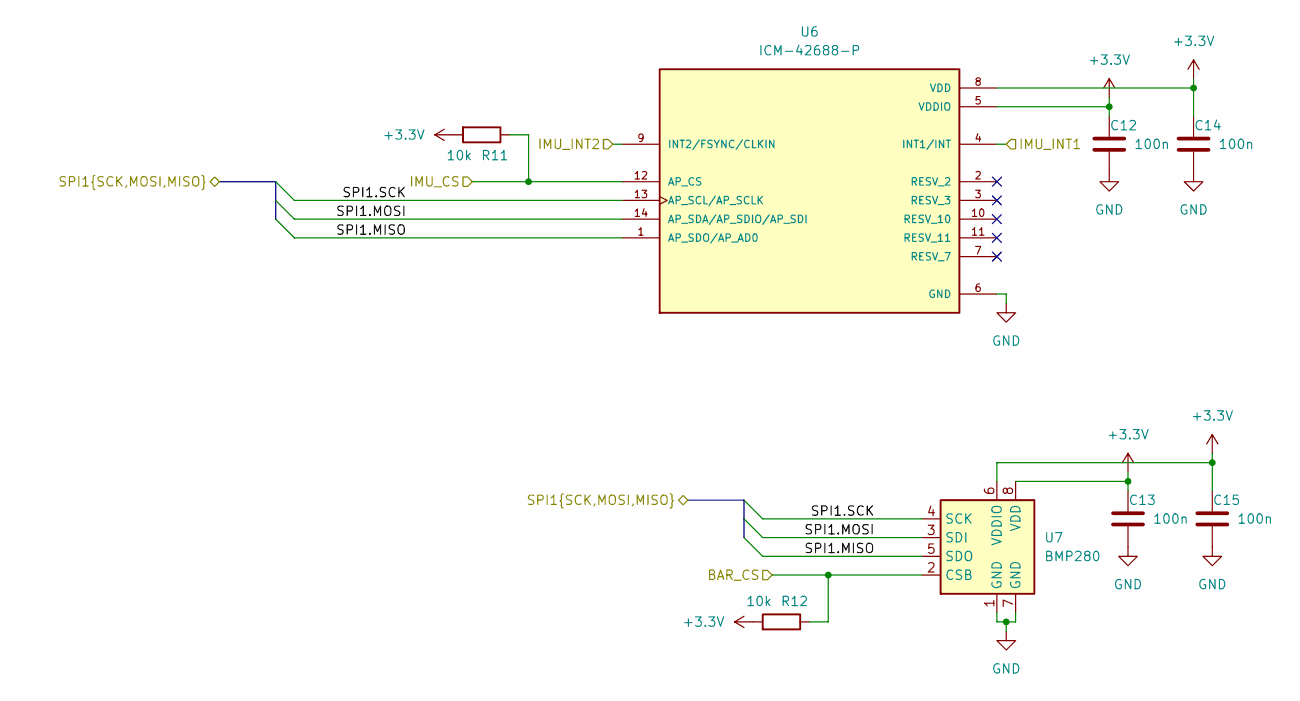
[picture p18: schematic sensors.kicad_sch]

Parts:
C12, C13, C14, C15: 100n; C_0201_0603Metric; MPN GRM033R61E104KE14D; LCSC C76939
R11, R12: 10k; R_0201_0603Metric; MPN RC0201FR-0710KL; LCSC C106225
U6: ICM-42688-P; PQFN50P300X250X97-14N; PARTREV 1.2
U7: BMP280; Bosch_LGA-8_2x2.5mm_P0.65mm_ClockwisePinNumbering

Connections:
+3.3V: C12.1, C13.1, C14.1, C15.1, R11.2, R12.2, U6.5 (VDDIO), U6.8 (VDD), U7.6 (VDDIO), U7.8 (VDD); also elsewhere on the board
/STM32/BAR_CS: R12.1, U7.2 (CSB); also elsewhere on the board
/STM32/IMU_CS: R11.1, U6.12 (AP_CS); also elsewhere on the board
/STM32/IMU_INT1: U6.4 (INT1/INT); also elsewhere on the board
/STM32/IMU_INT2: U6.9 (INT2/FSYNC/CLKIN); also elsewhere on the board
GND: C12.2, C13.2, C14.2, C15.2, U6.6 (GND), U7.1 (GND), U7.7 (GND); also elsewhere on the board
SPI1.MISO: U6.1 (AP_SDO/AP_AD0), U7.5 (SDO); also elsewhere on the board
SPI1.MOSI: U6.14 (AP_SDA/AP_SDIO/AP_SDI), U7.3 (SDI); also elsewhere on the board
SPI1.SCK: U6.13 (AP_SCL/AP_SCLK), U7.4 (SCK); also elsewhere on the board

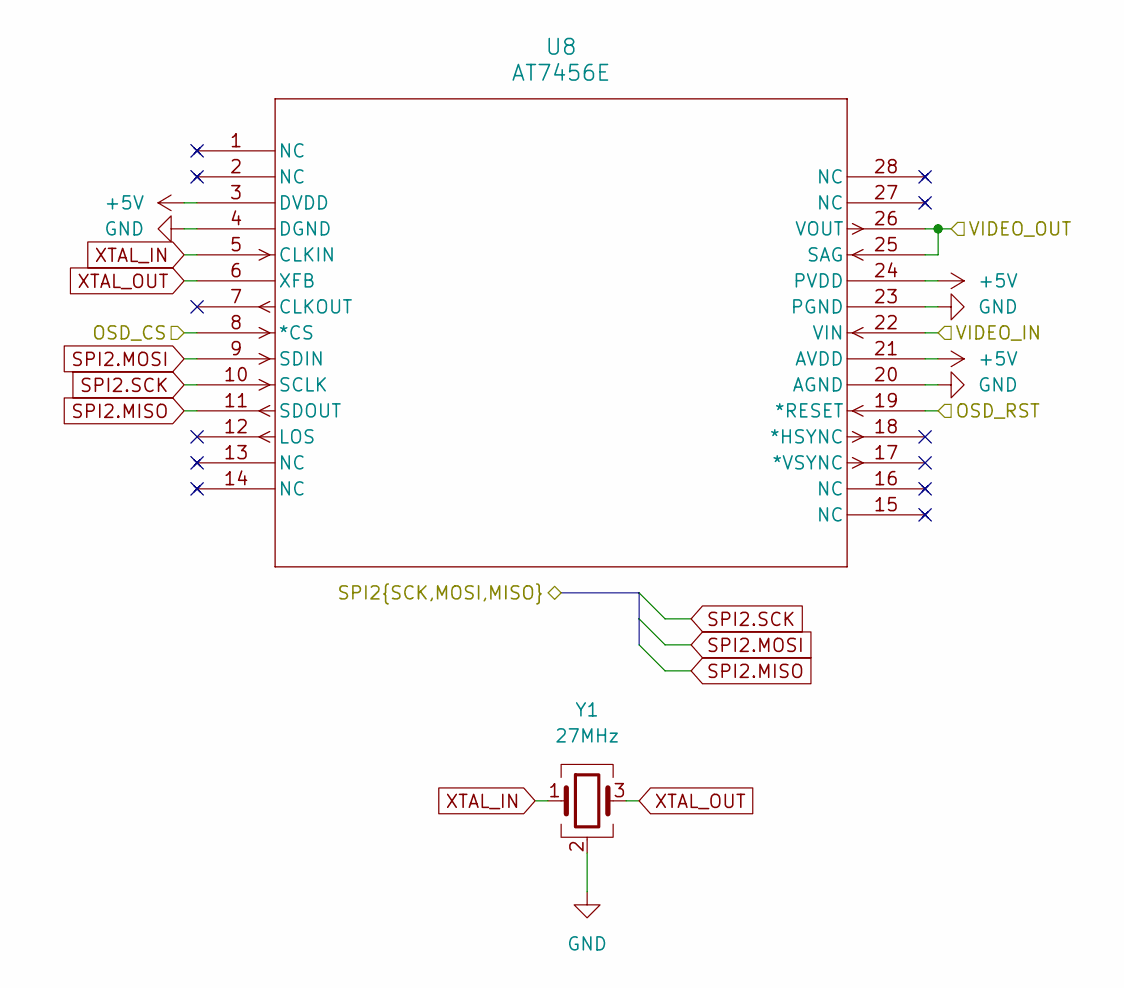
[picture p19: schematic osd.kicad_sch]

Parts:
U8: AT7456E; 21-0108G_U28E-5_MXM
Y1: 27MHz; Crystal_SMD_2016-4Pin_2.0x1.6mm

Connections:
+5V: U8.3 (DVDD), U8.21 (AVDD), U8.24 (PVDD); also elsewhere on the board
/OSD/OSD_CS: U8.8 (*CS); also elsewhere on the board
/OSD/OSD_RST: U8.19 (*RESET); also elsewhere on the board
/OSD/VIDEO_IN: U8.22 (VIN); also elsewhere on the board
/OSD/VIDEO_OUT: U8.25 (SAG), U8.26 (VOUT); also elsewhere on the board
GND: U8.4 (DGND), U8.20 (AGND), U8.23 (PGND), Y1.2 (G), Y1.4 (G); also elsewhere on the board
SPI2.MISO: U8.11 (SDOUT); also elsewhere on the board
SPI2.MOSI: U8.9 (SDIN); also elsewhere on the board
SPI2.SCK: U8.10 (SCLK); also elsewhere on the board
XTAL_IN: U8.5 (CLKIN), Y1.1
XTAL_OUT: U8.6 (XFB), Y1.3

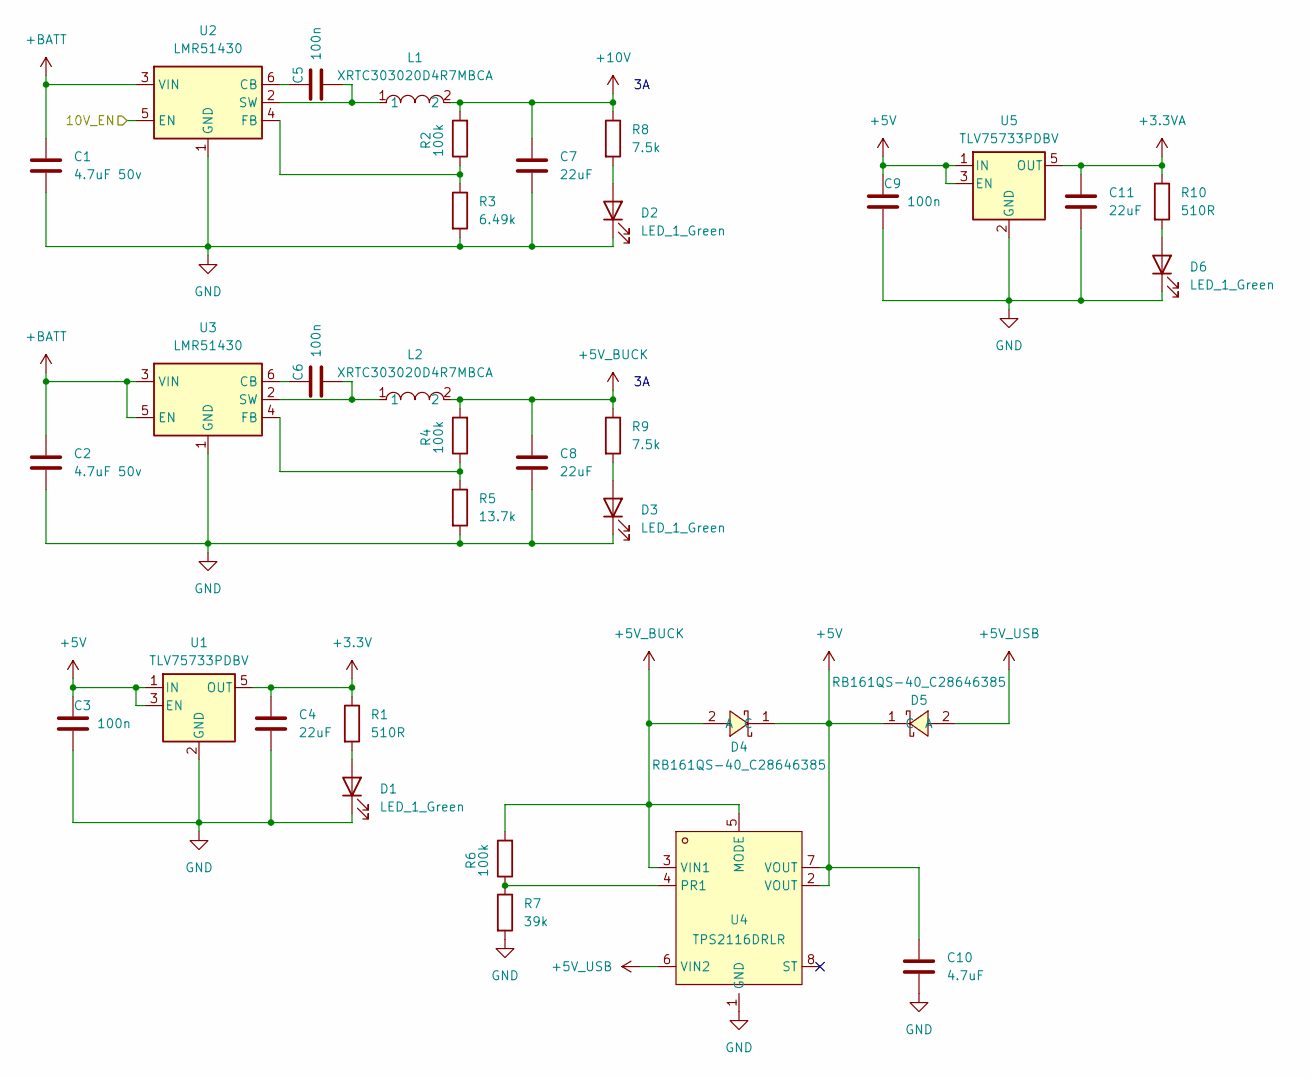
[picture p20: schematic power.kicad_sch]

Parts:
C1, C2: 4.7uF 50v; C_0805_2012Metric; MPN CL21A475KBQNNNE; LCSC C98192
C3, C5, C6, C9: 100n; C_0201_0603Metric; MPN GRM033R61E104KE14D; LCSC C76939
C4, C11: 22uF; C_0402_1005Metric; MPN GRM155R60J226ME11D; LCSC C415703
C7, C8: 22uF; C_0603_1608Metric; MPN CL10A226MO7JZNC; LCSC C2762594
C10: 4.7uF; C_0402_1005Metric; MPN CL05A475MP5NRNC; LCSC C23733
D1, D2, D3, D6: LED_1_Green; LED_0402_1005Metric; MPN XL-1005UGC; LCSC C965793
D4, D5: RB161QS-40_C28646385; D_SOD-882; MPN RB161QS-40; LCSC C28646385
L1, L2: XRTC303020D4R7MBCA; IND-SMD_L3.0-W3.0_AFE303020S; MPN XRTC303020D4R7MBCA; LCSC C39846837
R1, R10: 510R; R_0201_0603Metric; LCSC C57784
R2, R4, R6: 100k; R_0201_0603Metric; MPN 0201WMF1003TEE; LCSC C270364
R3: 6.49k; R_0201_0603Metric; LCSC C2107920
R5: 13.7k; R_0201_0603Metric; MPN RC-01W1372FT; LCSC C320695
R7: 39k; R_0201_0603Metric; MPN 0201WMF3902TEE; LCSC C473053
R8, R9: 7.5k; R_0201_0603Metric; LCSC C474437
U1, U5: TLV75733PDBV; SOT-23-5
U2, U3: LMR51430; SOT-23-6
U4: TPS2116DRLR; SOT-583-8_L2.1-W1.6-P0.50-LS1.6-BL; MPN TPS2116DRLR; LCSC C3235557

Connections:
+3.3V: C4.1, R1.1, U1.5 (OUT); also elsewhere on the board
+3.3VA: C11.1, R10.1, U5.5 (OUT); also elsewhere on the board
+5V: C3.1, C9.1, C10.1, D4.1 (C), D5.1 (C), U1.1 (IN), U1.3 (EN), U4.2 (VOUT), U4.7 (VOUT), U5.1 (IN), U5.3 (EN); also elsewhere on the board
+5V_BUCK: C8.1, D4.2 (A), L2.2, R4.2, R6.2, R9.1, U4.3 (VIN1), U4.5 (MODE)
+5V_USB: D5.2 (A), U4.6 (VIN2); also elsewhere on the board
+10V: C7.1, L1.2, R2.2, R8.1; also elsewhere on the board
+BATT: C1.1, C2.1, U2.3 (VIN), U3.3 (VIN), U3.5 (EN); also elsewhere on the board
/Power/10V_EN: U2.5 (EN); also elsewhere on the board
GND: C1.2, C2.2, C3.2, C4.2, C7.2, C8.2, C9.2, C10.2, C11.2, D1.1 (K), D2.1 (K), D3.1 (K), D6.1 (K), R3.2, R5.2, R7.2, U1.2 (GND), U2.1 (GND), U3.1 (GND), U4.1 (GND), U5.2 (GND); also elsewhere on the board
unnamed: D1.2 (A), R1.2
unnamed: D2.2 (A), R8.2
unnamed: D3.2 (A), R9.2
unnamed: D6.2 (A), R10.2
unnamed: C5.1, U2.6 (CB)
unnamed: R2.1, R3.1, U2.4 (FB)
unnamed: C5.2, L1.1, U2.2 (SW)
unnamed: C6.1, U3.6 (CB)
unnamed: R4.1, R5.1, U3.4 (FB)
unnamed: C6.2, L2.1, U3.2 (SW)
unnamed: R6.1, R7.1, U4.4 (PR1)

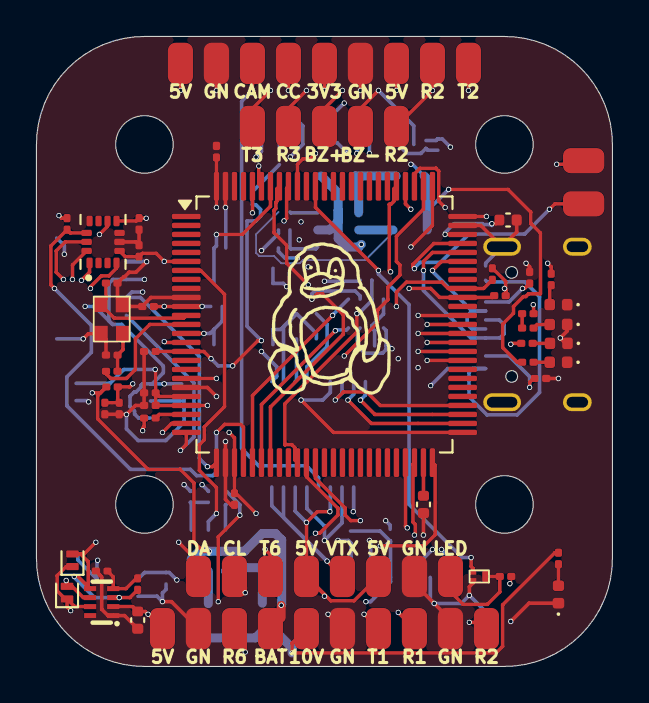
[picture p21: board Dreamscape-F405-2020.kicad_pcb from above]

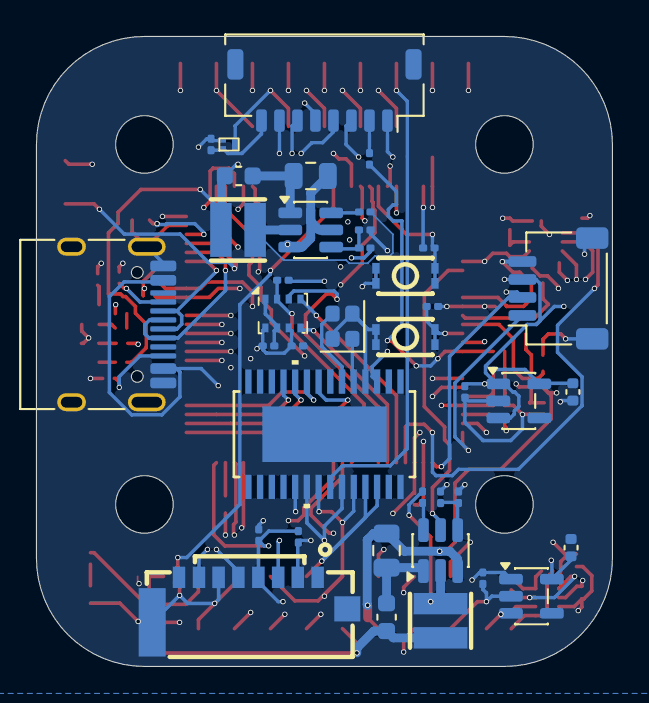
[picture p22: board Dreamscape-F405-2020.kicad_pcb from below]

Board: 6 copper layers, 32.0 x 35.0 mm, 121 parts (39 on the bottom side), 80 nets.
